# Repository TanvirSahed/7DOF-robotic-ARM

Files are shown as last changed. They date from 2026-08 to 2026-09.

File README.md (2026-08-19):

# 7-DOF Robotic Arm: Object Classification & Sorting

A 7-DOF robotic arm (MG996R servos, ATmega2560, PCA9685 driver) that detects and sorts
objects (cups vs. bottles) using MobileNet-SSDV3 for computer vision, controlled through
**feedback position mapping** instead of kinematic equations.

Published as:

> T. R. Sahed, S. R. Islam, M. T. I. Aronno, M. S. R. Chowdhury, "Object Classification by a
> 7-DOF Robotic Arm Using MobileNet-SSD and Feedback Position Mapping," 2025 International
> Conference on Quantum Photonics, Artificial Intelligence, and Networking (QPAIN), Rangpur,
> Bangladesh. DOI: [10.1109/QPAIN66474.2025.11171666](https://doi.org/10.1109/QPAIN66474.2025.11171666)

- 🎥 Demo video: https://youtube.com/shorts/5LcHwnB7o1Q
- 🧩 3D design (Fusion 360): https://a360.co/46bxGCI

Object detection: bottle
Object detection: cup

## How it works

- A WiFi smartphone camera streams video (IP Webcam) to a host PC running MobileNet-SSDV3
  (COCO-pretrained) to detect and classify cups/bottles in real time.
- **Feedback position mapping**: an extra feedback wire on each MG996R servo lets the
  microcontroller read its live angle. Target poses are recorded once by hand-positioning the
  arm, then replayed for pick-and-place, no kinematic equations needed.
- A PCA9685 driver regulates 6V/1.5A per channel across the 7 servos. The ATmega2560 receives
  the detected object's class over serial and drives a tuned PD controller (Kp=2.2, Kd=0.7)
  for smooth, low-jitter motion.

## Repository contents

| Path | What it is |
|---|---|
| `1RoboticArmFinal.ino` | Main Arduino Mega firmware: servo control, serial command handling, PD controller |
| `7DoFarmPositionMapping.ino` | Position-mapping sketch used to record joint angles for each pose |
| `RobotVision.py`, `RobotVision7Dof.py` | Host-side Python: MobileNet-SSD object detection + serial link to the Arduino |
| `arduinoCOM.py` | Serial communication helper |
| `coco.names.txt`, `frozen_inference_graph.pb` | MobileNet-SSD model/labels used for detection |
| `Object_Detection_Files.zip` | Bundled model config files |
| `ros2_ws/` | ROS 2 (Humble) URDF/xacro description of the arm, generated from the Fusion 360 CAD model, for RViz2 visualization and Gazebo simulation. See [`ros2_ws/src/7dof_description/README.md`](ros2_ws/src/7dof_description/README.md) |
| `bottle.JPG`, `cup.JPG`, `bottle_cup.JPG`, `bottle_arduino.JPG` | Detection sample images |

## Getting started

### Hardware / firmware

Flash `1RoboticArmFinal.ino` to an Arduino Mega with the servos wired per the pin mapping in
the sketch, then run the vision pipeline on the host PC:

```bash
python RobotVision7Dof.py
```

### ROS 2 visualization (no hardware required)

```bash
cd ros2_ws
colcon build --packages-select 7dof_description
source install/setup.bash
ros2 launch 7dof_description display.launch.py   # RViz2, with joint sliders
ros2 launch 7dof_description gazebo.launch.py     # Gazebo simulation
```

See [`ros2_ws/src/7dof_description/README.md`](ros2_ws/src/7dof_description/README.md) for
requirements and details.

## Results

- 81.25% object-detection accuracy, 90% sorting accuracy
- ~2-second sort cycle, 9/10 successful independent trials
- Sub-centimeter pose repeatability (mean error 0.53 cm, σ 0.44 cm over a 1,000-trial Monte Carlo simulation)
- 1.42 kg payload capacity

## Author

Md Tanvir Rahman Sahed, tanvir.sahed00@gmail.com

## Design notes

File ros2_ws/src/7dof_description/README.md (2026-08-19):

# 7dof_description: ROS 2 package

URDF/xacro description of the 7-DOF robotic arm used in this project, exported from the
Fusion 360 CAD assembly for visualization in RViz2 and simulation in Gazebo.

This package models the same arm covered in:

> T. R. Sahed, S. R. Islam, M. T. I. Aronno, M. S. R. Chowdhury, "Object Classification by a
> 7-DOF Robotic Arm Using MobileNet-SSD and Feedback Position Mapping," 2025 International
> Conference on Quantum Photonics, Artificial Intelligence, and Networking (QPAIN), Rangpur,
> Bangladesh. DOI: [10.1109/QPAIN66474.2025.11171666](https://doi.org/10.1109/QPAIN66474.2025.11171666)

- 3D design (Fusion 360): https://a360.co/46bxGCI
- Demo video: https://youtube.com/shorts/5LcHwnB7o1Q

The firmware and vision pipeline elsewhere in this repo drive the *physical* arm using
feedback position mapping (see the paper, Section III-D). This package is a separate
kinematic/visual model of the same geometry, useful for visualizing joint motion, planning,
or simulation, and not yet wired to the live hardware control loop.

## Contents

| Path | What it is |
|---|---|
| `urdf/7dof.xacro` | Main robot description (links, joints, visuals, collisions) |
| `urdf/7dof.trans` | Joint transmission definitions |
| `urdf/7dof.gazebo` | Gazebo-specific tags (materials, plugins) |
| `urdf/materials.xacro` | Link color/material definitions |
| `meshes/base_link.stl`, `meshes/arm_1_1.stl` … `arm_7_1.stl` | Per-link geometry, exported from Fusion 360 |
| `launch/display.launch.py` | `robot_state_publisher` + `joint_state_publisher_gui` + RViz2 |
| `launch/gazebo.launch.py` | Spawns the robot in Gazebo (classic) via `gazebo_ros` |
| `config/display.rviz` | Saved RViz view/display config used by `display.launch.py` |
| `config/gazebo.rviz` | Saved RViz config for the Gazebo view |
| `config/ros_gz_bridge_gazebo.yaml` | Topic bridge config for `ros_gz` (Gazebo Sim) |
| `package.xml`, `setup.py`, `setup.cfg`, `resource/` | Standard `ament_python` package files |
| `test/` | Boilerplate lint/style tests (`ament_lint_auto`) |

## Requirements

ROS 2 Humble (Ubuntu 22.04). Should work on other ROS 2 distros with minor tweaks.

```bash
sudo apt install ros-humble-xacro ros-humble-rviz2 ros-humble-robot-state-publisher \
  ros-humble-joint-state-publisher ros-humble-joint-state-publisher-gui \
  ros-humble-gazebo-ros-pkgs
```

## Build

Drop this package into the `src/` of a colcon workspace:

```bash
mkdir -p ~/ros2_ws/src
cp -r 7dof_description ~/ros2_ws/src/
cd ~/ros2_ws
colcon build --packages-select 7dof_description
source install/setup.bash
```

## Run

**RViz visualization**: spawns a GUI with sliders for every joint so you can pose the arm by hand:

```bash
ros2 launch 7dof_description display.launch.py
```

**Gazebo physics simulation**:

```bash
ros2 launch 7dof_description gazebo.launch.py
```

## Preview

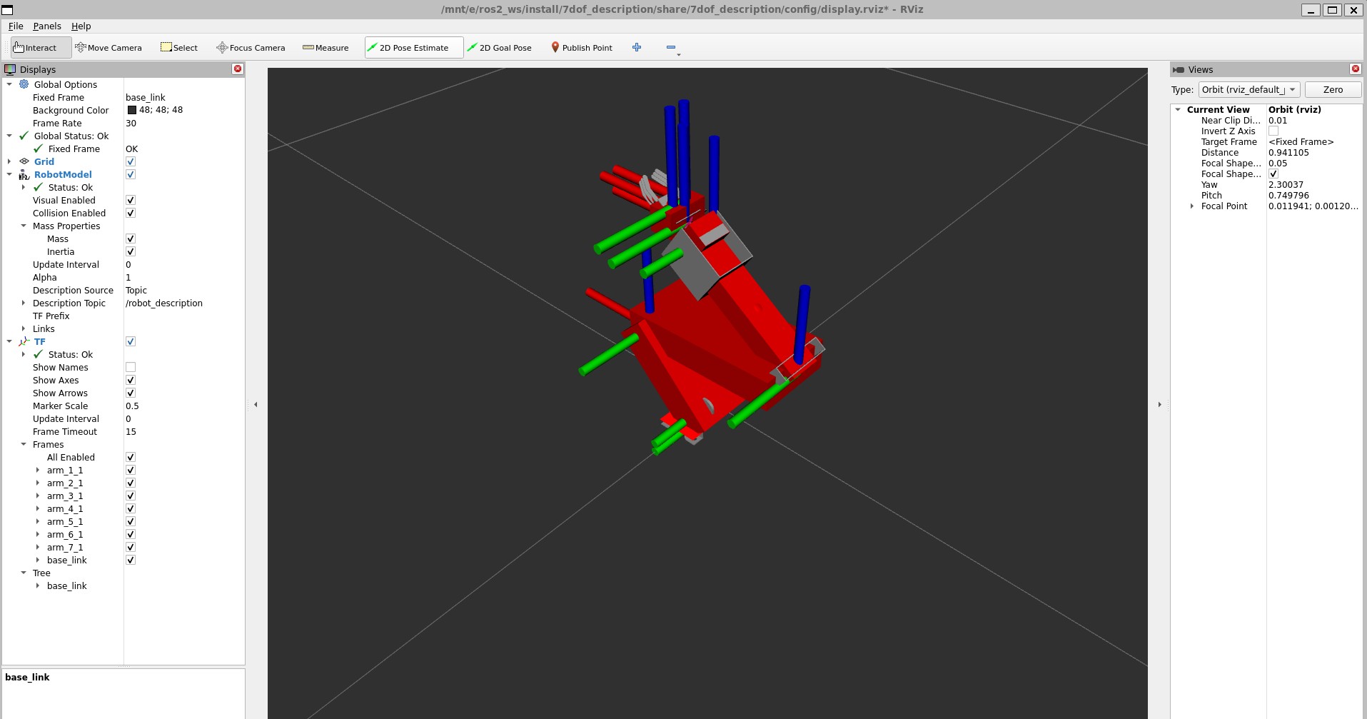
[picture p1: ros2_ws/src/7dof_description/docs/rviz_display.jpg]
RViz2: RobotModel and TF

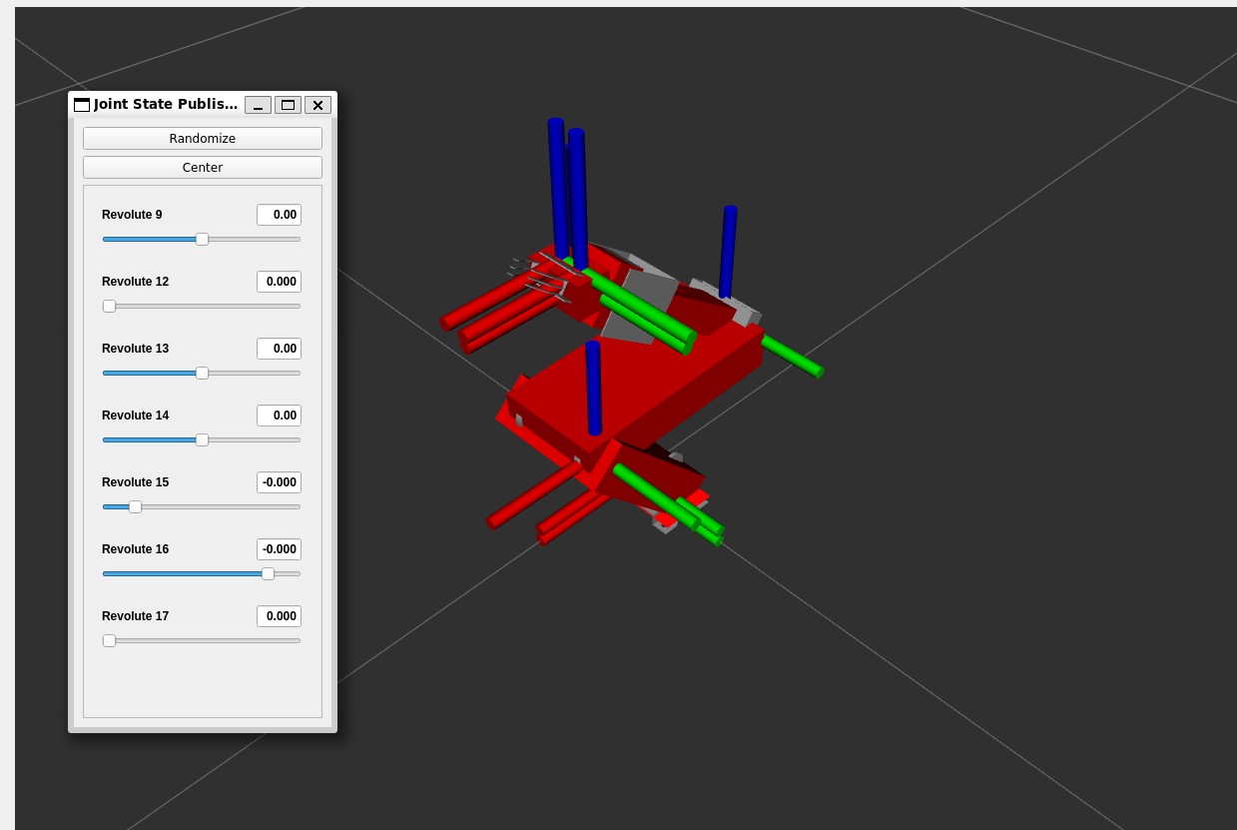
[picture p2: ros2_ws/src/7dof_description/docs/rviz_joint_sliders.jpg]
RViz2 with joint_state_publisher_gui sliders


## Notes

- `display.launch.py` defaults to `joint_state_publisher_gui` (slider window). Pass
  `gui:=false` to instead publish zeroed joint states without the GUI.
- The xacro is processed at launch time (`xacro.process_file(...)`), so editing
  `urdf/7dof.xacro` doesn't require a rebuild, just re-launch.

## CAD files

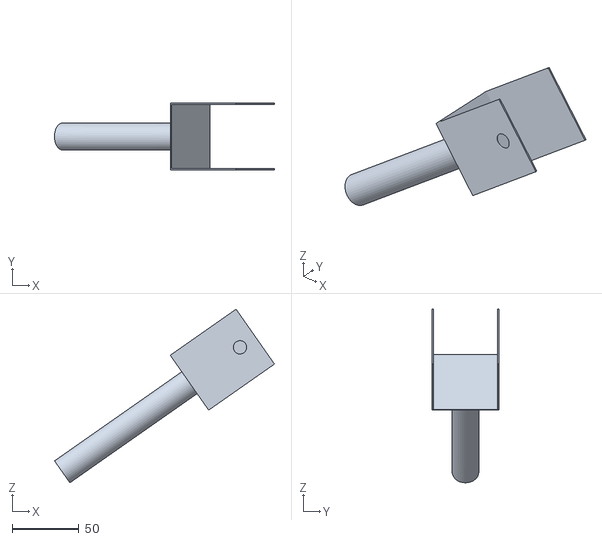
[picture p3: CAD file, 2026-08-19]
ros2_ws/src/7dof_description/meshes/arm_3_1.stl
164.2 x 50.0 x 129.6

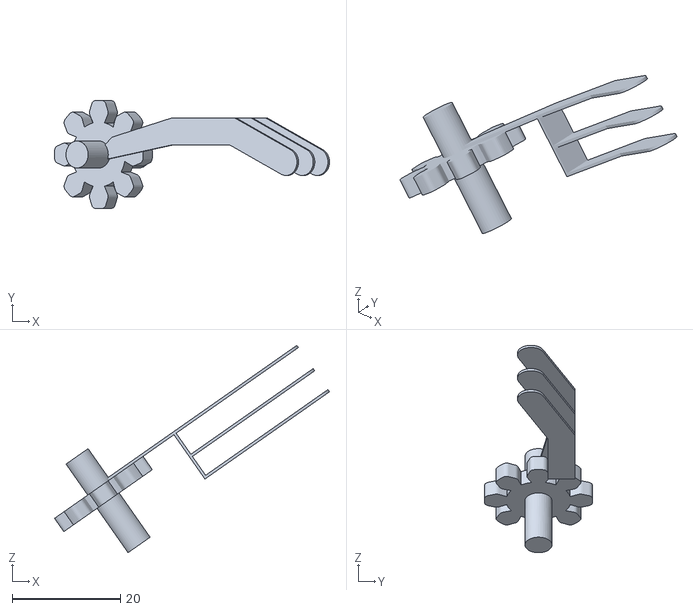
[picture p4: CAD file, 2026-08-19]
ros2_ws/src/7dof_description/meshes/arm_6_1.stl
50.9 x 20.0 x 38.4

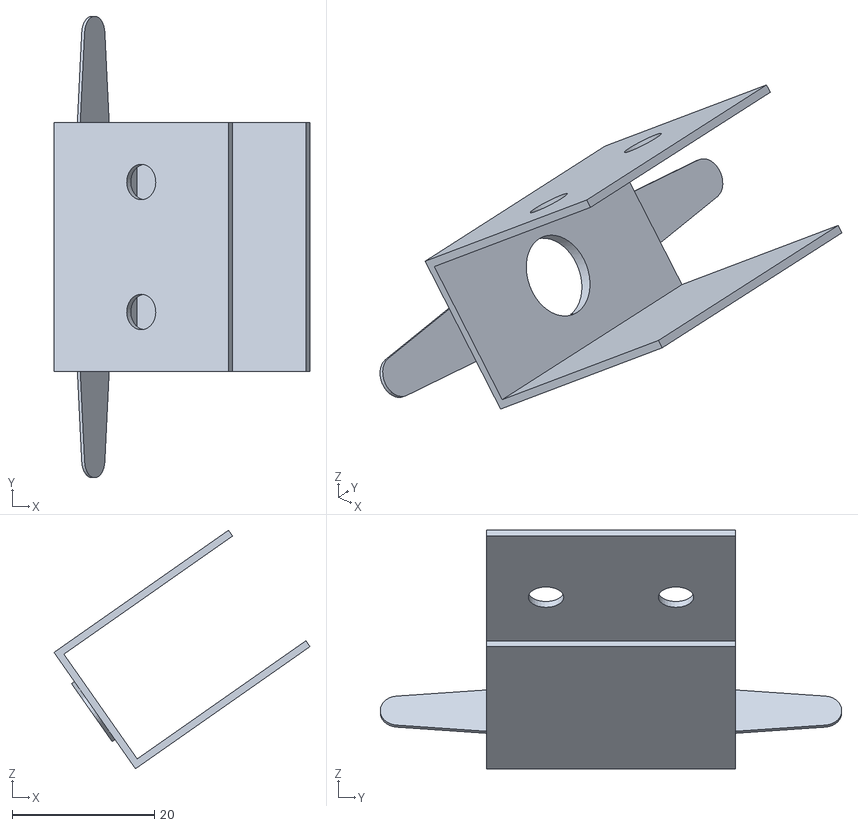
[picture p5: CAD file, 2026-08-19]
ros2_ws/src/7dof_description/meshes/arm_5_1.stl
36.0 x 65.0 x 33.6

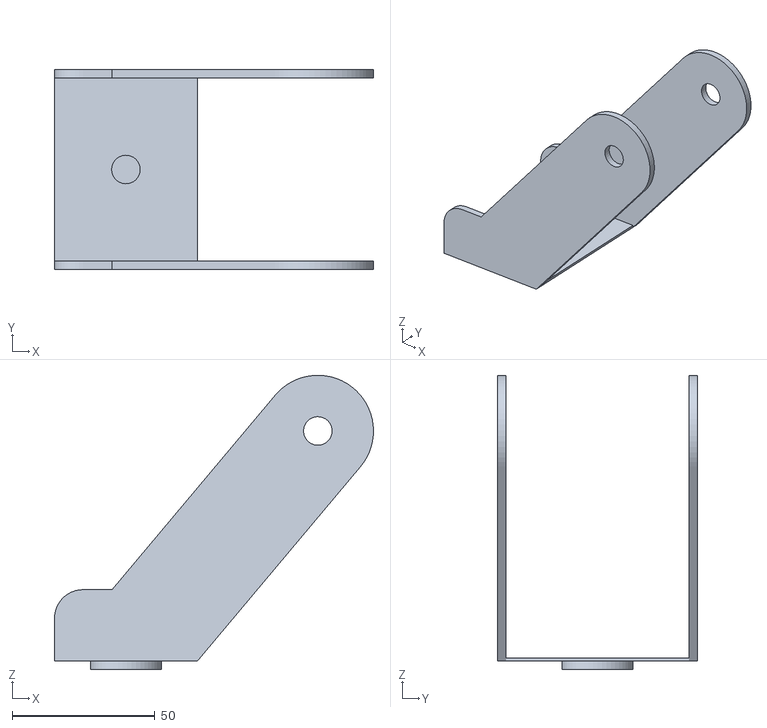
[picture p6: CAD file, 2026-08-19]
ros2_ws/src/7dof_description/meshes/arm_1_1.stl
111.6 x 70.0 x 103.0

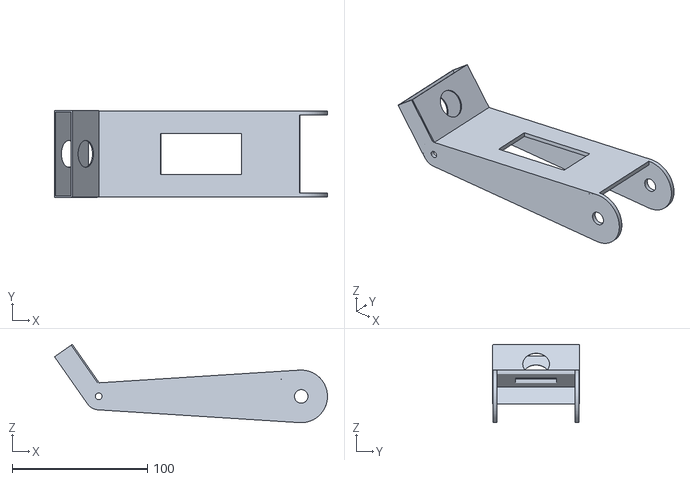
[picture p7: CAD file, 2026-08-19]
ros2_ws/src/7dof_description/meshes/arm_2_1.stl
202.2 x 64.2 x 58.0

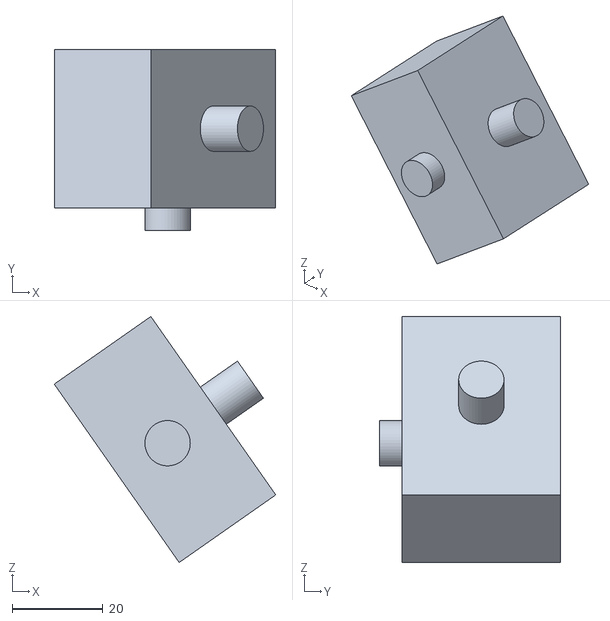
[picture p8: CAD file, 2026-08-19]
ros2_ws/src/7dof_description/meshes/arm_4_1.stl
48.8 x 40.0 x 54.2

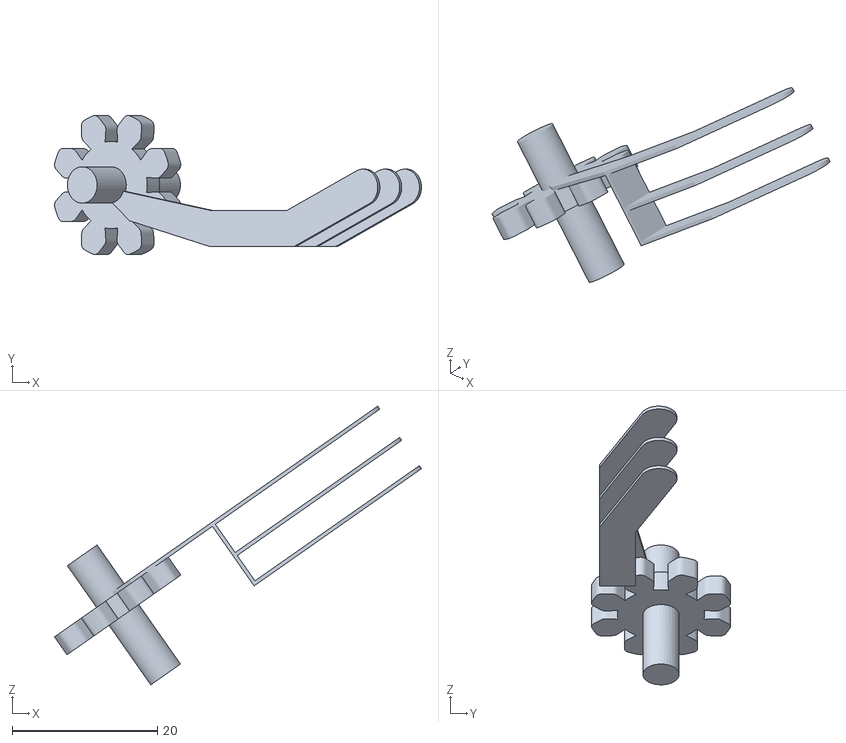
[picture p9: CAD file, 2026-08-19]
ros2_ws/src/7dof_description/meshes/arm_7_1.stl
50.5 x 19.1 x 38.4

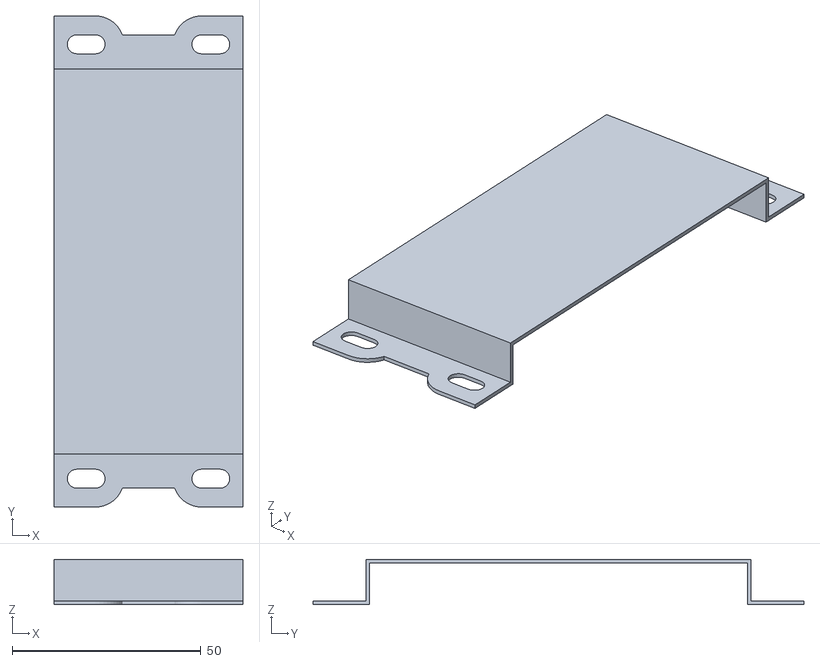
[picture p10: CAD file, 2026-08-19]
ros2_ws/src/7dof_description/meshes/base_link.stl
50.0 x 130.0 x 12.0

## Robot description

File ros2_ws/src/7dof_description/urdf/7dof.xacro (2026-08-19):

<?xml version="1.0" ?>
<robot name="7dof" xmlns:xacro="http://www.ros.org/wiki/xacro">

<xacro:include filename="$(find 7dof_description)/urdf/materials.xacro" />
<xacro:include filename="$(find 7dof_description)/urdf/7dof.trans" />
<xacro:include filename="$(find 7dof_description)/urdf/7dof.gazebo" />
<link name="base_link">
  <inertial>
    <origin xyz="-1.9615822388533525e-17 8.827120074840085e-17 0.009002899250958178" rpy="0 0 0"/>
    <mass value="0.01956038700343977"/>
    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
  </inertial>
  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
</link>

<link name="arm_1_1">
  <inertial>
    <origin xyz="0.02971251800470596 5.924914869048442e-17 0.0414323495110301" rpy="0 0 0"/>
    <mass value="0.09066295805207186"/>
    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
  </inertial>
  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
</link>

<link name="arm_3_1">
  <inertial>
    <origin xyz="0.05959283088497133 4.347405463805868e-05 0.04172707292226541" rpy="0 0 0"/>
    <mass value="0.12086262440631358"/>
    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
  </inertial>
  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
</link>

<link name="arm_4_1">
  <inertial>
    <origin xyz="-0.00031065124913117956 0.02232540295040704 0.0009929441828203378" rpy="0 0 0"/>
    <mass value="0.04754958307980198"/>
    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
  </inertial>
  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
</link>

<link name="arm_5_1">
  <inertial>
    <origin xyz="0.00956723756236743 4.879877418544239e-07 0.006536735298877272" rpy="0 0 0"/>
    <mass value="0.007583002778034214"/>
    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
  </inertial>
  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
</link>

<link name="arm_7_1">
  <inertial>
    <origin xyz="0.010202770809547769 -0.0009394516584164212 -0.004493000835550015" rpy="0 0 0"/>
    <mass value="0.003466288836036091"/>
    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
  </inertial>
  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
</link>

<link name="arm_6_1">
  <inertial>
    <origin xyz="0.010207004599050724 0.0005801178482570417 -0.00449297171362914" rpy="0 0 0"/>
    <mass value="0.00346329575383349"/>
    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
  </inertial>
  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
</link>

<link name="arm_2_1">
  <inertial>
    <origin xyz="-0.0766672536979728 -0.031996855183144685 0.006477186695577314" rpy="0 0 0"/>
    <mass value="0.1523954313332151"/>
    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
  </inertial>
  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
</link>

<joint name="Revolute 9" type="continuous">
  <origin xyz="0.0 0.0 0.012" rpy="0 0 0"/>
  <parent link="base_link"/>
  <child link="arm_1_1"/>
  <axis xyz="0.0 0.0 1.0"/>
</joint>

<joint name="Revolute 12" type="revolute">
  <origin xyz="-0.172696 -0.031888 0.014979" rpy="0 0 0"/>
  <parent link="arm_2_1"/>
  <child link="arm_3_1"/>
  <axis xyz="0.819152 0.0 0.573576"/>
  <limit upper="3.141593" lower="0.0" effort="100" velocity="100"/>
</joint>

<joint name="Revolute 13" type="revolute">
  <origin xyz="0.132763 -0.025 0.092961" rpy="0 0 0"/>
  <parent link="arm_3_1"/>
  <child link="arm_4_1"/>
  <axis xyz="0.0 1.0 0.0"/>
  <limit upper="1.570796" lower="-1.570796" effort="100" velocity="100"/>
</joint>

<joint name="Revolute 14" type="revolute">
  <origin xyz="0.018267 0.0225 0.014012" rpy="0 0 0"/>
  <parent link="arm_4_1"/>
  <child link="arm_5_1"/>
  <axis xyz="0.819152 0.0 0.573576"/>
  <limit upper="1.570796" lower="-1.570796" effort="100" velocity="100"/>
</joint>

<joint name="Revolute 15" type="revolute">
  <origin xyz="0.006961 -0.00915 0.017082" rpy="0 0 0"/>
  <parent link="arm_5_1"/>
  <child link="arm_7_1"/>
  <axis xyz="0.573576 0.0 -0.819152"/>
  <limit upper="1.570796" lower="-0.261799" effort="100" velocity="100"/>
</joint>

<joint name="Revolute 16" type="revolute">
  <origin xyz="0.006961 0.00915 0.017082" rpy="0 0 0"/>
  <parent link="arm_5_1"/>
  <child link="arm_6_1"/>
  <axis xyz="0.573576 0.0 -0.819152"/>
  <limit upper="0.261799" lower="-1.570796" effort="100" velocity="100"/>
</joint>

<joint name="Revolute 17" type="revolute">
  <origin xyz="0.067151 0.032 0.083527" rpy="0 0 0"/>
  <parent link="arm_1_1"/>
  <child link="arm_2_1"/>
  <axis xyz="0.0 1.0 0.0"/>
  <limit upper="1.570796" lower="0.0" effort="100" velocity="100"/>
</joint>

</robot>

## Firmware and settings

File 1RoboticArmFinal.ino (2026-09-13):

/* =============================================================================
   7-DOF Robotic Arm — PD position control

   Control law per joint, evaluated every DT_MS:
       e = r - y
       u = Kp*e + Kd*(de)
       command = clamp(r + u)
   where r is the trajectory setpoint for this tick and y is the joint angle
   measured through the servo feedback wire on the analog input.

   PD stays disabled until the ADC-to-degree constants below are filled in.
   With it disabled, every joint command passes straight through and the arm
   runs purely open-loop.

   ---------------------------------------------------------------------------
   BRING-UP ORDER
     1. CALIB_MODE 1      -> run, record printed SLOPE/OFFSET, paste below
     2. CALIBRATION_DONE 1, CALIB_MODE 0
     3. STEP_TEST_MODE 1  -> log step responses, tune KP then KD
     4. STEP_TEST_MODE 0  -> normal operation with PD active
   ---------------------------------------------------------------------------
   WIRING: signal pins 2..8 drive s1..s7. Feedback wires land on A0..A6 for
   s1..s7. Verify this mapping with a meter before enabling PD — a swapped
   pair means each joint reads the other's angle and the correction pushes
   the wrong way.
============================================================================= */

#include <Servo.h>

/* ----------------------------- BUILD OPTIONS ----------------------------- */
#define CALIBRATION_DONE  0   // 1 after pasting measured SLOPE/OFFSET values
#define CALIB_MODE        0   // 1 = run calibration sweep instead of main loop
#define STEP_TEST_MODE    0   // 1 = run step-response logger instead of main loop
#define KD_TIME_BASED     0   // 0 = de per sample, 1 = de/dt per second
#define RESET_SEQ_STATE   0   // 1 = allow repeat picks after a full cycle

/* ------------------------------ PD GAINS --------------------------------- */
/* Kd scale depends on KD_TIME_BASED:
     0 -> Kd multiplies (e - ePrev)          [deg per deg/sample]
     1 -> Kd multiplies (e - ePrev)/DT_S     [deg per deg/s]
   At DT = 20 ms the two forms differ by a factor of 50, so a Kd tuned for
   one is meaningless in the other. 0.7 belongs to the per-sample form.      */
const float KP = 2.2f;
const float KD = 0.7f;

/* --------------------------- CONTROL TIMING ------------------------------ */
const uint16_t DT_MS       = 20;     // control period, aligned to the 50 Hz servo frame
const float    DT_S        = DT_MS / 1000.0f;
const float    MS_PER_DEG  = 10.0f;  // ramp rate: 10 ms of travel per degree
const uint16_t SETTLE_MS   = 100;    // hold the endpoint under PD to drive out residual error
const uint8_t  FB_SAMPLES  = 8;      // ADC averages per read; the pot is noisy while driven
const float    DEADBAND    = 1.5f;   // deg; below MG996R resolution, treat as zero error
const float    D_ALPHA     = 0.80f;  // derivative low-pass; 0 = none, 0.9 = heavy
const float    U_CLAMP     = 25.0f;  // deg; ceiling on the correction term itself

/* ------------------------------- JOINTS ---------------------------------- */
const uint8_t NJ = 7;
enum { J1 = 0, J2, J3, J4, J5, J6, J7 };

Servo sv[NJ];
const uint8_t SIG_PIN[NJ] = { 2, 3, 4, 5, 6, 7, 8 };
const uint8_t FB_PIN[NJ]  = { A0, A1, A2, A3, A4, A5, A6 };

/* Soft limits, set from the angle range each joint actually uses plus margin.
   These bound the PD output so a large transient error cannot drive a joint
   into its end stop.                                                        */
const float LIM_LO[NJ] = {   0.0f,  20.0f,  20.0f,   0.0f,  60.0f,   0.0f, 110.0f };
const float LIM_HI[NJ] = { 180.0f, 160.0f, 160.0f, 180.0f, 180.0f, 180.0f, 180.0f };

/* Home pose, one entry per joint. */
const float HOME[NJ] = { 90.0f, 30.0f, 150.0f, 90.0f, 180.0f, 0.0f, 180.0f };

/* ------------------------ FEEDBACK CALIBRATION --------------------------- */
/* Converts the raw 0..1023 ADC reading on the feedback wire into degrees:
       angle_deg = SLOPE[j] * raw + OFFSET[j]
   Values below are placeholders. Run CALIB_MODE and replace them.           */

// float SLOPE[NJ]  = { 0.461f, 0.493f, 0.414f, 0.325f, 0.386f, 0.473f, 0.466f }; // my calib constants 
// float OFFSET[NJ] = { -88.1f, -80.3f, -86.6f, -98.3f, -94.6f, -82.5f, -84.1f }; // my calib constants
float SLOPE[NJ]  = { 0.450f, 0.450f, 0.450f, 0.450f, 0.450f, 0.450f, 0.450f }; // replace with your recorded value and turn the CALIBRATION_DONE flag 1
float OFFSET[NJ] = { -45.0f, -45.0f, -45.0f, -45.0f, -45.0f, -45.0f, -45.0f }; // replace with your recorded value and turn the CALIBRATION_DONE flag 1

/* ------------------------------ STATE ------------------------------------ */
float cmd[NJ];              // last angle written to each joint
float ePrev[NJ];            // previous error, per joint
float dFilt[NJ];            // filtered derivative, per joint
bool  pdActive = false;     // gated on calibration constants being real

String names;               // incoming control character from the host
unsigned int tym;           // window timer for the serial listen phases
int x = 0;                  // bottle sequence step
int y = 0;                  // cup sequence step

/* ========================= LOW-LEVEL PRIMITIVES ========================== */

static float readDeg(uint8_t j) {
  uint16_t acc = 0;
  for (uint8_t k = 0; k < FB_SAMPLES; k++) acc += analogRead(FB_PIN[j]);
  float raw = (float)acc / (float)FB_SAMPLES;
  return SLOPE[j] * raw + OFFSET[j];
}

static void resetPD(uint8_t j) { ePrev[j] = 0.0f; dFilt[j] = 0.0f; }
static void resetPDAll()       { for (uint8_t j = 0; j < NJ; j++) resetPD(j); }

/* One PD evaluation. r is this tick's setpoint; returns the angle to command.
   Returns r untouched when PD is disabled.                                  */
static float pdCorrect(uint8_t j, float r) {
  if (!pdActive) return r;

  float y_meas = readDeg(j);
  float e = r - y_meas;
  if (fabs(e) < DEADBAND) e = 0.0f;

#if KD_TIME_BASED
  float dE = (e - ePrev[j]) / DT_S;
#else
  float dE = (e - ePrev[j]);
#endif
  /* Raw differencing at 50 Hz turns pot noise into a large fake derivative,
     so the term is low-passed before Kd is applied.                         */
  dFilt[j] = D_ALPHA * dFilt[j] + (1.0f - D_ALPHA) * dE;
  ePrev[j] = e;

  float u = KP * e + KD * dFilt[j];
  u = constrain(u, -U_CLAMP, U_CLAMP);
  return constrain(r + u, LIM_LO[j], LIM_HI[j]);
}

static void writeJoint(uint8_t j, float angle) {
  int deg = (int)lround(angle);
  deg = constrain(deg, 0, 180);
  sv[j].write(deg);
  cmd[j] = angle;
}

/* Fixed-cadence tick. Absorbs the ADC read time so the control period holds
   at DT_MS no matter how many joints were sampled this cycle.               */
static void tickWait(uint32_t &tNext) {
  while ((int32_t)(millis() - tNext) < 0) { /* spin */ }
  tNext += DT_MS;
}

/* ========================== MOTION PRIMITIVES ============================ */

/* Ramps one joint to target. Duration scales with travel distance, giving a
   constant commanded velocity of one degree per MS_PER_DEG.                 */
void moveJoint(uint8_t j, float target) {
  float start = cmd[j];
  float span  = fabs(target - start);
  uint32_t dur = (uint32_t)(span * MS_PER_DEG);
  if (dur < DT_MS) dur = DT_MS;

  uint32_t t0 = millis();
  uint32_t tNext = t0 + DT_MS;

  for (;;) {
    uint32_t el = millis() - t0;
    float frac = (el >= dur) ? 1.0f : (float)el / (float)dur;
    float r = start + (target - start) * frac;

    writeJoint(j, pdCorrect(j, r));
    if (frac >= 1.0f) break;
    tickWait(tNext);
  }

  uint32_t tEnd = millis() + SETTLE_MS;
  while ((int32_t)(millis() - tEnd) < 0) {
    writeJoint(j, pdCorrect(j, target));
    tickWait(tNext);
  }
  /* Book the logical position as the setpoint, not the corrected command,
     so the next ramp starts from a clean number.                            */
  cmd[j] = target;
}

/* Shoulder pair: J3 mirrors J2 about 180 deg. Both joints get their own PD
   evaluation against their own feedback wire.                               */
void movePair(float target2) {
  float start2 = cmd[J2];
  float span   = fabs(target2 - start2);
  uint32_t dur = (uint32_t)(span * MS_PER_DEG);
  if (dur < DT_MS) dur = DT_MS;

  uint32_t t0 = millis();
  uint32_t tNext = t0 + DT_MS;

  for (;;) {
    uint32_t el = millis() - t0;
    float frac = (el >= dur) ? 1.0f : (float)el / (float)dur;
    float r2 = start2 + (target2 - start2) * frac;
    float r3 = 180.0f - r2;

    writeJoint(J2, pdCorrect(J2, r2));
    writeJoint(J3, pdCorrect(J3, r3));
    if (frac >= 1.0f) break;
    tickWait(tNext);
  }

  uint32_t tEnd = millis() + SETTLE_MS;
  while ((int32_t)(millis() - tEnd) < 0) {
    writeJoint(J2, pdCorrect(J2, target2));
    writeJoint(J3, pdCorrect(J3, 180.0f - target2));
    tickWait(tNext);
  }
  cmd[J2] = target2;
  cmd[J3] = 180.0f - target2;
}

/* Snaps every joint to the home pose. PD state is cleared because the
   commanded position jumps here — a carried-over derivative would fire a
   large spurious correction on the next move.                               */
void rst() {
  for (uint8_t j = 0; j < NJ; j++) {
    sv[j].write((int)HOME[j]);
    cmd[j] = HOME[j];
  }
  resetPDAll();
}

/* ============================== SEQUENCES ================================ */

void pick_bottle() {
  if (x == 0)  { rst(); delay(600); x = 1;  }
  if (x == 1)  { moveJoint(J1, 120); x = 2;  }   //  90 -> 120
  if (x == 2)  { moveJoint(J5,  70); x = 3;  }   // 180 ->  70
  if (x == 3)  { moveJoint(J7, 120); x = 4;  }   // 180 -> 120, gripper closes
  if (x == 4)  { movePair(150);      x = 5;  }   // J2  30 -> 150
  if (x == 5)  { moveJoint(J7, 170); x = 6;  }   // 120 -> 170
  if (x == 6)  { movePair(90);       x = 7;  }   // J2 150 ->  90
  if (x == 7)  { moveJoint(J1, 180); x = 8;  }   // 120 -> 180, swing to drop zone
  if (x == 8)  { movePair(150);      x = 9;  }   // J2  90 -> 150
  if (x == 9)  { moveJoint(J7, 120); x = 10; }   // 170 -> 120, release
  if (x == 10) { rst();              x = 11; }
#if RESET_SEQ_STATE
  if (x == 11) { x = 0; }
#endif
}

void pick_cup() {
  if (y == 0)  { rst(); delay(600); y = 1;  }
  if (y == 1)  { moveJoint(J1,  45); y = 2;  }   //  90 ->  45
  if (y == 2)  { moveJoint(J5,  70); y = 3;  }   // 180 ->  70
  if (y == 3)  { moveJoint(J7, 120); y = 4;  }   // 180 -> 120, gripper closes
  if (y == 4)  { movePair(150);      y = 5;  }   // J2  30 -> 150
  if (y == 5)  { moveJoint(J7, 170); y = 6;  }   // 120 -> 170
  if (y == 6)  { movePair(90);       y = 7;  }   // J2 150 ->  90
  if (y == 7)  { moveJoint(J1,   0); y = 8;  }   //  45 ->   0, swing to drop zone
  if (y == 8)  { movePair(150);      y = 9;  }   // J2  90 -> 150
  if (y == 9)  { moveJoint(J7, 120); y = 10; }   // 170 -> 120, release
  if (y == 10) { rst();              y = 11; }
#if RESET_SEQ_STATE
  if (y == 11) { y = 0; }
#endif
}

/* ============================== SETUP ==================================== */

bool PD_RUNTIME_OK();   // forward declaration

void setup() {
  Serial.begin(115200);

  for (uint8_t j = 0; j < NJ; j++) {
    sv[j].attach(SIG_PIN[j]);
    pinMode(SIG_PIN[j], OUTPUT);
    pinMode(FB_PIN[j], INPUT);
    cmd[j] = HOME[j];
  }
  resetPDAll();

#if CALIBRATION_DONE
  pdActive = PD_RUNTIME_OK();
#else
  pdActive = false;
#endif

  tym = millis();
  delay(200);
  rst();

#if CALIB_MODE || STEP_TEST_MODE
  delay(1000);
#endif
}

/* Refuses to enable PD while the conversion constants are still placeholders.
   Feeding garbage degrees into the error term would slam joints into their
   limits on the first tick.                                                 */
bool PD_RUNTIME_OK() {
  for (uint8_t j = 0; j < NJ; j++) {
    if (fabs(SLOPE[j] - 0.450f) < 1e-6f && fabs(OFFSET[j] + 45.0f) < 1e-6f) {
      Serial.println(F("[WARN] placeholder calibration detected - PD disabled"));
      return false;
    }
  }
  Serial.println(F("[OK] PD active"));
  return true;
}

/* ========================== CALIBRATION ROUTINE ========================== */
/* Parks each joint at three known angles inside its soft limits, averages the
   ADC at each, fits a straight line through the low and high points, and
   prints the constants. The mid point is used only as a linearity check.    */
#if CALIB_MODE
void runCalibration() {
  Serial.println(F("=== FEEDBACK CALIBRATION ==="));
  Serial.println(F("joint, angLo, rawLo, angMid, rawMid, angHi, rawHi, slope, offset, midErrDeg"));

  for (uint8_t j = 0; j < NJ; j++) {
    float aLo  = LIM_LO[j] + 5.0f;
    float aHi  = LIM_HI[j] - 5.0f;
    float aMid = 0.5f * (aLo + aHi);
    float ang[3] = { aLo, aMid, aHi };
    float raw[3];

    for (uint8_t k = 0; k < 3; k++) {
      sv[j].write((int)lround(ang[k]));
      delay(1200);                              // let the joint arrive and stop moving
      uint32_t acc = 0;
      for (uint8_t n = 0; n < 32; n++) { acc += analogRead(FB_PIN[j]); delay(5); }
      raw[k] = (float)acc / 32.0f;
    }

    float slope  = (ang[2] - ang[0]) / (raw[2] - raw[0]);
    float offset = ang[0] - slope * raw[0];
    float midErr = (slope * raw[1] + offset) - ang[1];

    Serial.print(j + 1); Serial.print(F(", "));
    for (uint8_t k = 0; k < 3; k++) {
      Serial.print(ang[k], 1); Serial.print(F(", "));
      Serial.print(raw[k], 1); Serial.print(F(", "));
    }
    Serial.print(slope, 6);  Serial.print(F(", "));
    Serial.print(offset, 3); Serial.print(F(", "));
    Serial.println(midErr, 2);

    sv[j].write((int)HOME[j]);
    delay(600);
  }
  Serial.println(F("=== paste slope/offset columns into SLOPE[] / OFFSET[] ==="));
  Serial.println(F("midErrDeg above ~3 deg means a non-linear pot - use a LUT instead"));
}
#endif

/* ========================= STEP-RESPONSE LOGGER ========================== */
/* Holds one joint at a fixed setpoint after a step and logs r, y, e and the
   command every DT_MS as CSV. Run one joint at a time with the rest parked
   at home, raise KP until the response is quick without overshoot, then
   raise KD to damp what is left.                                            */
#if STEP_TEST_MODE
const uint8_t  TEST_JOINT = J1;
const float    STEP_FROM  = 90.0f;
const float    STEP_TO    = 180.0f;
const uint16_t LOG_MS     = 2000;

void runStepTest() {
  Serial.println(F("t_ms,r,y,e,u"));
  writeJoint(TEST_JOINT, STEP_FROM);
  delay(1000);
  resetPD(TEST_JOINT);

  uint32_t t0 = millis();
  uint32_t tNext = t0 + DT_MS;
  while (millis() - t0 < LOG_MS) {
    float r  = STEP_TO;
    float yv = readDeg(TEST_JOINT);
    float u  = pdCorrect(TEST_JOINT, r);
    writeJoint(TEST_JOINT, u);

    Serial.print(millis() - t0); Serial.print(',');
    Serial.print(r, 2);          Serial.print(',');
    Serial.print(yv, 2);         Serial.print(',');
    Serial.print(r - yv, 2);     Serial.print(',');
    Serial.println(u, 2);

    tickWait(tNext);
  }
  Serial.println(F("=== step test complete ==="));
}
#endif

/* =============================== LOOP ==================================== */
/* Listens for a class character from the host for 5 s, runs the matching
   sequence, then listens again for a second object.

   x and y terminate at 11 and are not cleared, so each object is picked once
   per power cycle. Set RESET_SEQ_STATE 1 for repeat picks.                  */

void loop() {

#if CALIB_MODE
  runCalibration();
  while (1) { }
#elif STEP_TEST_MODE
  runStepTest();
  while (1) { }
#else

  while ((millis() - tym) <= 5000) {
    if (Serial.available()) {
      names = Serial.readStringUntil('\r');
    }
  }
  tym = millis();

  if (names == "a") {
    pick_bottle();
    tym = millis();
    while ((millis() - tym) <= 5000) {
      if (Serial.available()) names = Serial.readStringUntil('\r');
    }
    tym = millis();
    if (names == "c") { delay(2000); pick_cup(); }
  }

  else if (names == "b") {
    pick_bottle();
    tym = millis();
    while ((millis() - tym) <= 5000) {
      if (Serial.available()) names = Serial.readStringUntil('\r');
    }
    tym = millis();
    if (names == "c")      { delay(2000); pick_cup();    }
    else if (names == "b") { delay(2000); pick_bottle(); }
  }

  else if (names == "c") {
    pick_cup();
    tym = millis();
    while ((millis() - tym) <= 5000) {
      if (Serial.available()) names = Serial.readStringUntil('\r');
    }
    tym = millis();
    if (names == "b")      { delay(2000); pick_bottle(); }
    else if (names == "c") { delay(2000); pick_cup();    }
  }

#endif
}
